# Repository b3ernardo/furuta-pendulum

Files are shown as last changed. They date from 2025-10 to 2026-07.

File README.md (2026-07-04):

# Furuta Pendulum

Implementation of the **Furuta Pendulum** project, developed as part of my undergraduate thesis in Control and Automation Engineering.  
The goal is to model, simulate, and implement real-time control of a Furuta Pendulum using an **ESP32** microcontroller.

---

## 📂 Repository Structure

- **/3d_print** → STL files for 3D printing the physical structure of the Furuta Pendulum prototype.
- **/arduino_code/furuta** → Contains the control algorithm implemented on the ESP32 (Arduino IDE).  
  - **furuta.ino** → Main code that runs the real-time LQR control loop, reads encoder data, applies PWM signals to the motor, logs measurements, and sends data via serial.
- **/matlab_simulink** → MATLAB scripts and Simulink models for system modeling, simulation, and validation.  
  - **LQR.mlx** → Computes the optimal LQR gain matrix.  
  - **simulation_linear_model.slx** → Simulink model for the linearized system.  
  - **simulation_non_linear_model.slx** → Simulink model for the nonlinear system.  
  - **data_log_pulse.txt** / **data_log_step.txt** → Experimental data collected from pulse and step disturbance tests.  
  - **plots_pulse.mlx** / **plots_step.mlx** → Scripts for generating comparative plots (simulation vs. experimental data).  
- **/python_code** → Scripts for data acquisition from the ESP32 via serial communication.  
  - **get_data.ipynb** / **get_data.py** → Identical scripts for collecting and saving real-time data from the ESP32 to `data_log.txt`. 

---

## 🛠️ Features

- State-space modeling and linearization of the Furuta Pendulum.  
- LQR (Linear Quadratic Regulator) control design.  
- Real-time implementation on ESP32 using PWM and rotary encoders.  
- Complete 3D-printable structure for assembling the physical prototype.

---

## ⚙️ How It Works

1. The ESP32 runs the control loop at 100 Hz (Ts = 10 ms), reading angular positions and velocities from encoders.  
2. The control signal is computed via LQR feedback and applied to the motor driver using PWM modulation.  
3. Disturbances (step or pulse) can be injected to evaluate controller performance.  
4. The ESP32 sends sampled data through the serial interface, which is logged by the Python script.  
5. The collected data can then be analyzed and compared with Simulink simulations.

---

## 🎯 Purpose

This project was developed as an **educational platform for Control Engineering**, combining theoretical modeling, simulation, and practical implementation.  
It enables students and enthusiasts to reproduce the experiment, understand nonlinear dynamics, and test advanced control techniques in a real embedded environment.

---

## 🧠 Author

Developed by **Bernardo Silva**  
Control and Automation Engineering — UFMG  
LinkedIn: [Bernardo Silva](https://www.linkedin.com/in/bernardo-de-souza-silva/)

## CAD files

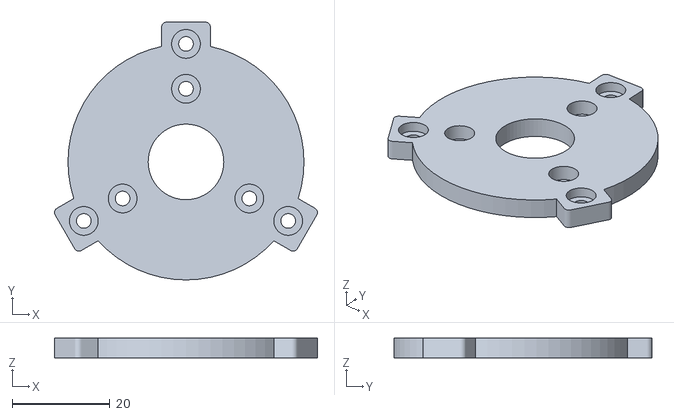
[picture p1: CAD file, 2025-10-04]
3d_print/Furuta - TampaCilindro.stl
53.9 x 52.9 x 4.00

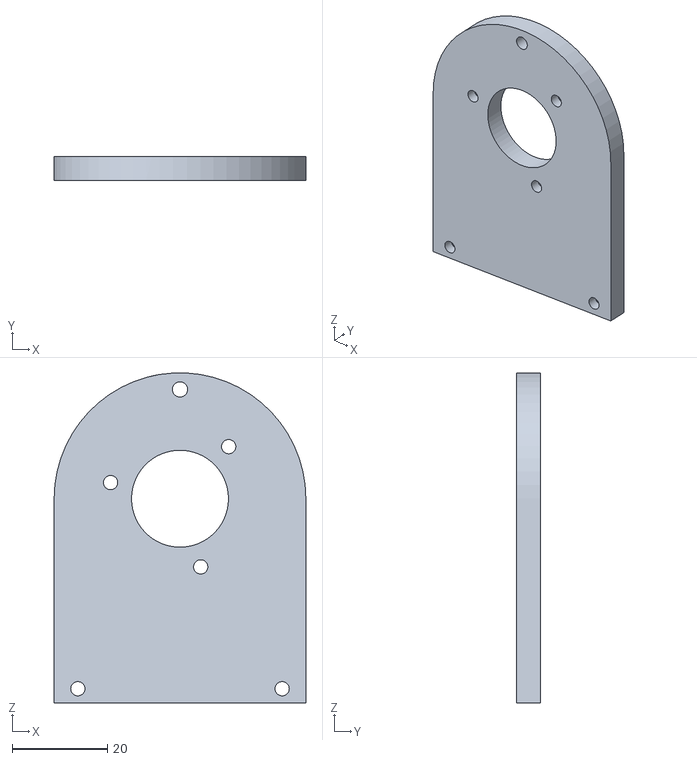
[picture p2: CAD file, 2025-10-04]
3d_print/Furuta - SuporteEncoder.stl
53.0 x 5.00 x 69.5

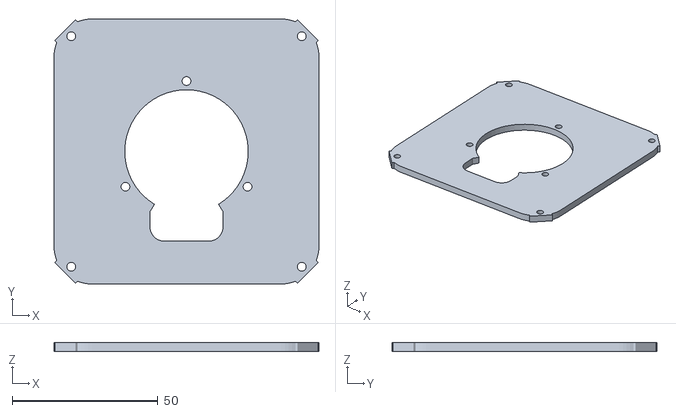
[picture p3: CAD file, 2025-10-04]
3d_print/Furuta - TampaBase.stl
91.0 x 91.0 x 3.00

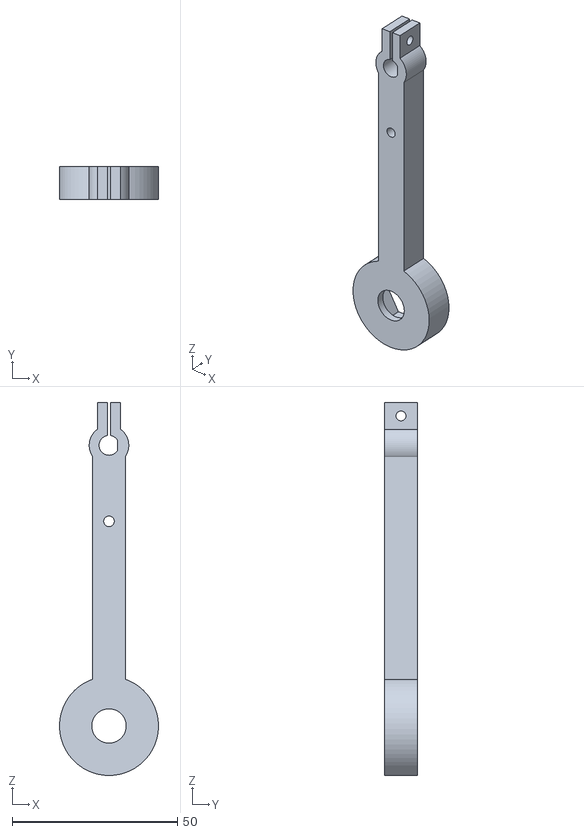
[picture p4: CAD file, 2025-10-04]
3d_print/Furuta - Haste.stl
30.0 x 10.0 x 113.0

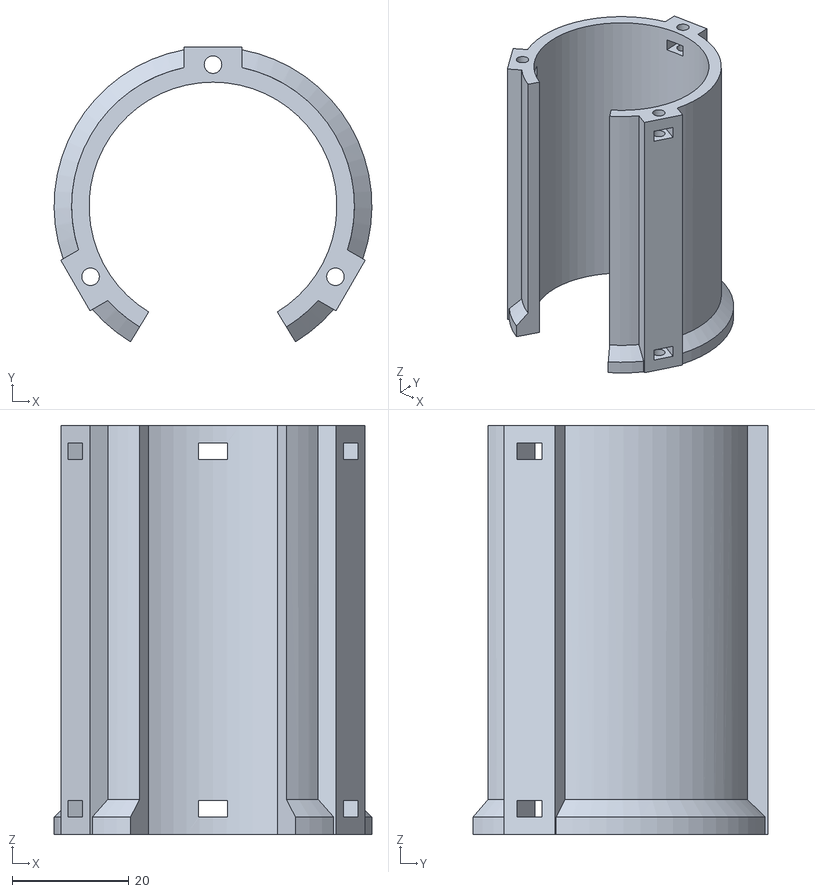
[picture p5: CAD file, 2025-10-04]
3d_print/Furuta - Cilindro.stl
54.4 x 50.5 x 70.0

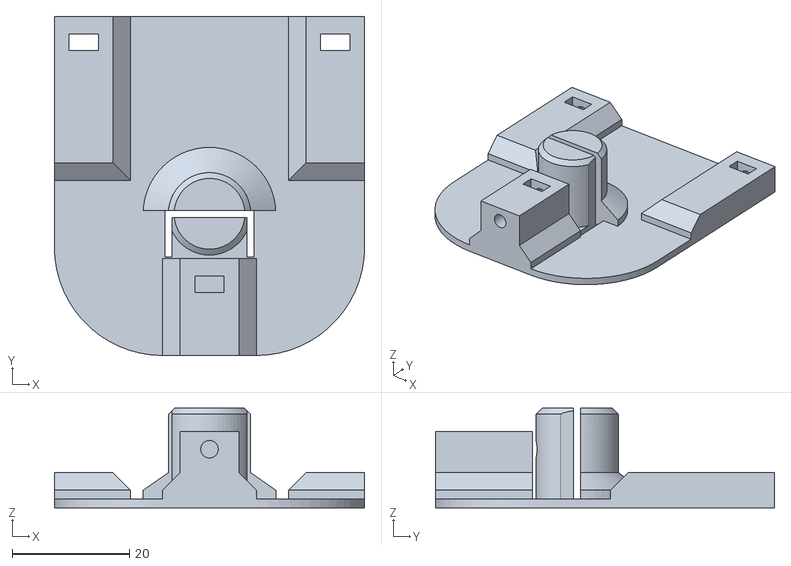
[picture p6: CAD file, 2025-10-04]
3d_print/Furuta - BracoRotativo.stl
53.0 x 57.9 x 17.0

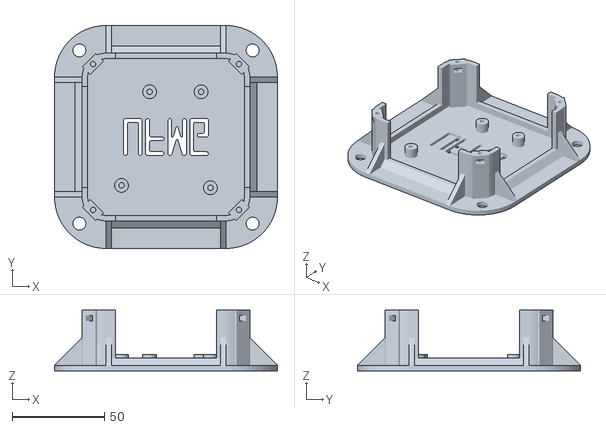
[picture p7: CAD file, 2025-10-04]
3d_print/Furuta - Base.stl
121.0 x 121.0 x 33.0

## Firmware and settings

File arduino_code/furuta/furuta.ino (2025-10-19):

/*
  ============================================
  UFMG FURUTA-Kit is placed under the MIT License
  Copyright (c) 2024 by GTI (UFMG)
  ============================================
  Hardware:
  * 1 ESP-WROOM-32 WEMOS D1 R32 development board
  * 1 Nidec 24-H
  * 1 Rotary Incremental Encoder
*/

// Include the encoder library for ESP32, which uses built-in hardware counters
#include <ESP32Encoder.h>

// Pin for the onboard ESP32 LED (blue LED on GPIO 2)
#define INTERNAL_LED 2

// PWM configuration for NIDEC motor driver
#define NIDEC_TIMER_BIT 8      // PWM resolution: 8-bit (0–255)
#define NIDEC_BASE_FREQ 20000  // PWM frequency: 20 kHz (to avoid audible noise)

// NIDEC motor control pins
#define BRAKE 18        // Brake pin (Start/Stop control)
#define NIDEC_PWM 19    // PWM output pin
#define DIR 23          // Direction pin (Forward/Reverse)
#define NCHA 13         // Motor encoder channel A
#define NCHB 5          // Motor encoder channel B
#define NIDEC_PWM_CH 1  // PWM channel used for ESP32 LEDC

// Encoder pins for the pendulum rod
#define RCHA 32  // Rod encoder channel A
#define RCHB 33  // Rod encoder channel B

#define MAX_SAMPLES 3000  // Maximum number of data samples stored

// Encoder objects
ESP32Encoder NIDEC_ENC;  // Encoder for the NIDEC motor
ESP32Encoder ROD_ENC;    // Encoder for the pendulum rod

// Conversion rad to deg
const float RAD2DEG = 180.0f / PI;  // ≈ 57.2958

// Safety limits (in degrees)
const float BASE_LIMIT_DEG = 160.0f;  // Max angle for the NIDEC motor (±)
const float ROD_LIMIT_DEG = 20.0f;    // Max angle for the pendulum (±)

// Encoder counts per revolution (adjust according to your measurement!)
const float CPR_NIDEC = 400.0f;  // Motor encoder (100 PPR ×4 = 400)
const float CPR_ROD = 1440.0f;   // Rod encoder (360 PPR ×4 = 1440)

// Counts per radian (used to convert counts → radians)
const float CNT_PER_RAD_NIDEC = CPR_NIDEC / (2.0f * PI);  // ≈ 63.66
const float CNT_PER_RAD_ROD = CPR_ROD / (2.0f * PI);      // ≈ 229.18

// Control gains - LQR
float K1 = -0.5111;
float K2 = 14.1924;
float K3 = -0.3557;
float K4 = 0.9390;

// Variables to store encoder readings, PWM output, and accumulated states
float rod_position = 0;    // Current angular position of the pendulum rod (incremental encoder counts)
float nidec_position = 0;  // Current angular position of the NIDEC motor
float nidec_speed = 0;
float rod_speed = 0;
float pwm = 0;        // Control signal to be sent to the motor driver (PWM duty cycle)
int NIDEC_count = 0;  // Raw encoder count for NIDEC motor in the current sample
int ROD_count = 0;    // Raw encoder count for pendulum rod in the current sample

// Sampling time variables
float Ts = 0.01;        // Sampling time (control loop period) in seconds → 10 ms
float currentT = 0.0;   // Current loop timestamp (milliseconds converted to seconds)
float previousT = 0.0;  // Previous loop timestamp (used to calculate elapsed time)

// Variables used for data logging and transmission
float data[MAX_SAMPLES][7];  // Matrix storing up to 3000 samples, each with 7 measured or computed variables
float disturbance = 0;       // External disturbance applied to the system (e.g., pulse or step input)
float Tc = 20;               // Data acquisition period (ms) used to control when samples are sent via Serial
float currentTc = 0.0;       // Current timestamp used for timing control
float previousTc = 0.0;      // Previous timestamp used to determine when to send data
int count = 0;               // Sample counter used to track the number of stored measurements

// MAIN SETUP: Runs once on startup/reset
void setup() {
  Serial.begin(9600);  // Start Serial Monitor for debugging

  // Initialize motor and encoders
  NIDECsetup();
  ENCsetup();

  // Configure internal LED
  pinMode(INTERNAL_LED, OUTPUT);
  digitalWrite(INTERNAL_LED, HIGH);  // Turn on LED (indicates system is starting)

  // Wait until the rod encoder has moved enough counts before starting
  while (abs(ROD_count) < 600) {
    ROD_count = ROD_ENC.getCount();
  }

  // Blink LED for system ready indication
  delay(1000);
  digitalWrite(INTERNAL_LED, LOW);
  delay(1000);
  digitalWrite(INTERNAL_LED, HIGH);
  delay(1000);
  digitalWrite(INTERNAL_LED, LOW);

  // Reset encoder counters
  NIDEC_ENC.clearCount();
  ROD_ENC.clearCount();
}

// MAIN LOOP: Runs repeatedly after setup
void loop() {
  balance();
  // print();
}

// BALANCE CONTROL LOOP: Runs the main control algorithm for the Furuta pendulum
void balance() {
  currentT = millis();  // Current time in ms

  // Run control loop every Ts seconds
  if ((currentT - previousT) / 1000.0 >= Ts) {
    previousT = currentT;

    // Safety: stop system if rod or motor goes beyond safe angle limits
    if (abs(nidec_position * RAD2DEG) < BASE_LIMIT_DEG && abs(rod_position * RAD2DEG) < ROD_LIMIT_DEG) {
      digitalWrite(BRAKE, HIGH);  // Enable motor brake

      // Read encoder increments (speed since last loop = position increment per sampling interval)
      nidec_speed = -NIDEC_ENC.getCount() / (Ts * CNT_PER_RAD_NIDEC);
      rod_speed = ROD_ENC.getCount() / (Ts * CNT_PER_RAD_ROD);

      // Reset encoders for next loop
      NIDEC_ENC.clearCount();
      ROD_ENC.clearCount();

      // Integrate speed to get angular position
      nidec_position += nidec_speed * Ts;
      rod_position += rod_speed * Ts;

      // Compute control law (state feedback)
      float u = K1 * nidec_position + K2 * rod_position + K3 * nidec_speed + K4 * rod_speed;

      // Conversion to PWM
      pwm = -constrain(u * 21.25, -200, 200);

      // Apply small random correction if motor stalls
      if (nidec_speed == 0) {
        pwm += random(8) - 4;
      }

      // Apply a step-type disturbance after 21 seconds
      // if (currentT / 1000.0 > 21) {
      //   disturbance = 1 * 21.25;
      // }

      // Apply a pulse-type disturbance at t ∈ (21s, 22s)
      // if (currentT / 1000.0 > 21 && currentT / 1000.0 < 22) {
      //   disturbance = 1 * 21.25;
      // } else {
      //   disturbance = 0;
      // }

      // Send command to motor
      MOTORcmd(pwm + disturbance);
    } else {
      // If system goes out of bounds → stop motor and activate LED alarm
      pwm = 0;
      MOTORcmd(pwm);  // Stop motor
      digitalWrite(BRAKE, LOW);
      digitalWrite(INTERNAL_LED, HIGH);  // Activate LED alarm
    }

    // Data logging after 20 seconds of operation
    // if (currentT / 1000.0 > 20) {
    //   data[count][0] = currentT / 1000.0;  // Time (s)
    //   data[count][1] = nidec_position;     // Base angle (rad)
    //   data[count][2] = rod_position;       // Rod angle (rad)
    //   data[count][3] = nidec_speed;        // Base angular speed (rad/s)
    //   data[count][4] = rod_speed;          // Rod angular speed (rad/s)
    //   data[count][5] = pwm / 21.25;        // Normalized control signal
    //   data[count][6] = disturbance;        // Applied disturbance

    //   if (count < MAX_SAMPLES - 1) {
    //     count++;
    //   }
    // }
  }
}

// DATA PRINT FUNCTION: Sends all collected samples to Serial Monitor after 50s
void print() {
  currentTc = millis();

  // Print data every Tc seconds, only after 50 seconds of operation
  if ((currentTc - previousTc) / 1000.0 >= Tc && currentTc / 1000.0 > 50) {
    previousTc = currentTc;

    // Send data matrix (time, positions, speeds, control, disturbance)
    for (int i = 0; i < MAX_SAMPLES; i++) {
      for (int j = 0; j < 7; j++) {
        Serial.print(data[i][j], 6);  // Print with 6 decimal places

        if (j != 6) {
          Serial.print(" ");
        }
      }
      Serial.println();
    }

    Serial.println("===");  // End of data block marker
  }
}

// NIDEC MOTOR SETUP
void NIDECsetup() {
  pinMode(BRAKE, OUTPUT);
  digitalWrite(BRAKE, HIGH);  // Enable brake initially

  pinMode(DIR, OUTPUT);
  ledcSetup(NIDEC_PWM_CH, NIDEC_BASE_FREQ, NIDEC_TIMER_BIT);
  ledcAttachPin(NIDEC_PWM, NIDEC_PWM_CH);
  MOTORcmd(0);  // Start with motor stopped

  // Setup motor encoder
  ESP32Encoder::useInternalWeakPullResistors = puType::up;
  NIDEC_ENC.attachFullQuad(NCHA, NCHB);
  NIDEC_ENC.clearCount();
}

// ROD ENCODER SETUP
void ENCsetup() {
  ESP32Encoder::useInternalWeakPullResistors = puType::up;
  ROD_ENC.attachFullQuad(RCHA, RCHB);
  ROD_ENC.clearCount();
}

/*
  --------------------------------------------------------------------------------------------------
  | Control signal (sp) | DIR pin | PWM value (ledcWrite) | Motor result                           |
  |---------------------|---------|-----------------------|----------------------------------------|
  | -200                | LOW     | 200                   | Motor spins in direction A, high power |
  | -50                 | LOW     | 50                    | Motor spins in direction A, low power  |
  | 0                   | none    | 0                     | Motor stopped                          |
  | +50                 | HIGH    | 50                    | Motor spins in direction B, low power  |
  | +200                | HIGH    | 200                   | Motor spins in direction B, high power |
  --------------------------------------------------------------------------------------------------
*/

// MOTOR COMMAND FUNCTION: The code makes an adjustment to the PWM because the driver hardware interprets the inverted values
void MOTORcmd(int sp) {
  // Set direction
  if (sp < 0) {
    digitalWrite(DIR, LOW);
    sp = -sp;  // Make speed positive
  } else {
    digitalWrite(DIR, HIGH);
  }

  // Apply PWM signal (inverted due to motor driver configuration)
  ledcWrite(NIDEC_PWM_CH, int(sp > 255 ? 0 : 255 - sp));
}
